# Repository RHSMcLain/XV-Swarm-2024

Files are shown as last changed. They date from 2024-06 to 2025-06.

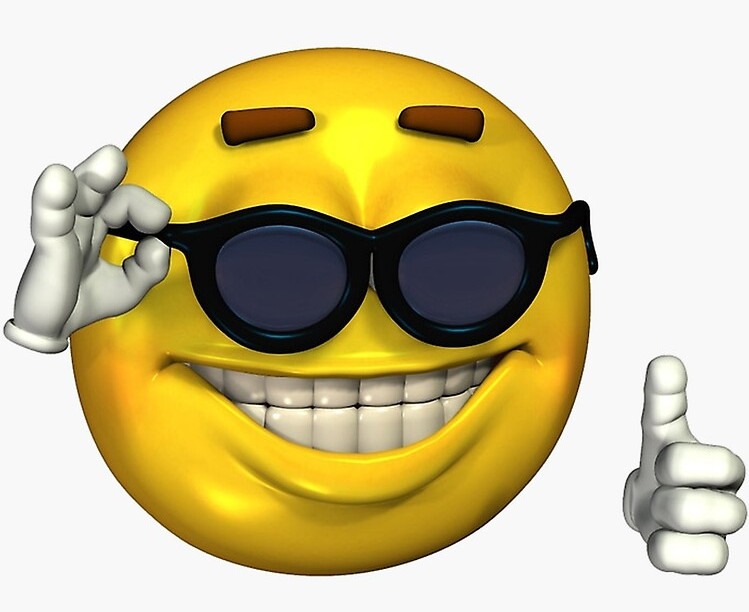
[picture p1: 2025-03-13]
Python/Resources/connecteddrone.jpg

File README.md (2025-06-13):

header
<!Happy now Bob?>
##
<details>  
    <summary>
        <b>Description of XV: Swarm</b>
    </summary>
    <p>&nbsp;&nbsp;&nbsp;&nbsp;&nbsp; The objective of this class was to create and program swarm drones ourselves. For the first few weeks of class, we worked on building &nbsp;&nbsp;&nbsp;&nbsp;&nbsp;the drones using a parts kit put together through research. To legally fly the drone, we needed approval for multiple FAA and school &nbsp;&nbsp;&nbsp;&nbsp;&nbsp;district waivers, some of which had to be revised. We also created the code from scratch, including the keyboard and flight stick &nbsp;&nbsp;&nbsp;&nbsp;&nbsp;controls, the communications from the Arduino to the flight controller, the access point, and the base station.</p>
</details>

<details>
    <summary> <b>Setup for programming<br></b> </summary>
        <setup>
            &nbsp;&nbsp;&nbsp;&nbsp;&nbsp;What you need to install:
        <details>
                <summary>Python Libraries</summary>
                <p>
                            pip3 install "requests>=2.*" <br>
                            pip3 install netifaces <i>(make sure you have C++ build tools and the SDK for your version if you are on windows)</i> <br>
                            python3 -m pip install customtkinter <br>
                            python3 -m pip install --upgrade Pillow <br>
                            pip3 install pynput <br>
                </p>
            </details>
        </setup>
</details>

<details> 
    <summary>
        <b>Regulatory Compliance</b>
    </summary>
      &nbsp;&nbsp;&nbsp;&nbsp;&nbsp;What we have applied for and received:<br>
    &nbsp;&nbsp;&nbsp;&nbsp;&nbsp;- FAA Multi-Use Waiver<br>
    &nbsp;&nbsp;&nbsp;&nbsp;&nbsp;- RSD Multi-Use Waiver<br>
    &nbsp;&nbsp;&nbsp;&nbsp;&nbsp;- § 107.35 – Operation of Multiple Small UAS<br>
    &nbsp;&nbsp;&nbsp;&nbsp;&nbsp;- Registered each drone With FAA<br>
    &nbsp;&nbsp;&nbsp;&nbsp;&nbsp;- Registered RSD with ODA<br>
    &nbsp;&nbsp;&nbsp;&nbsp;&nbsp;- FRIA zone <br>

</details>

<details> 
    <summary>
        <b>Summary of Flightstick Code</b>
    </summary>
    <p>&nbsp;&nbsp;&nbsp;&nbsp;&nbsp; Code for flight stick that outputs value for  pitch, roll, yaw, and throttle for the drone. </p>

</details>

<details> 
    <summary>
        <b>Summary of Base Station Code</b>
    </summary>
    <p><span style=width: 40px; display: inline-block;></span><span>Code for the base station and keyboard controls for pitch, roll, yaw, and throttle. The base station is responsible for transmitting and receiving signals to and from the drone's coverage area.</span></p>

</details>

<details> 
    <summary>
        <b>Summary of Access Point Code</b>
    </summary>
    <p>&nbsp;&nbsp;&nbsp;&nbsp;&nbsp; The access point provides WIFI, collects based station IP, and shares the base station IP with the drone. This code makes all of these possible. </p>

</details>

<details>
    <summary>
        <h3>Drone Building Instructions and Parts List</h3>
    </summary>
    <details>
        <summary>
            <b>Frame Construction</b>
        </summary>
        &nbsp;&nbsp;&nbsp;&nbsp;&nbsp;<a href="https://github.com/RHSMcLain/XV-Swarm-2024/blob/main/Instructions/FrameConstruction.md">Frame Instructions</a>
    </details>
    <details>
        <summary>
            <b>Wiring!</b>
        </summary>
        &nbsp;&nbsp;&nbsp;&nbsp;&nbsp;<a href="https://github.com/RHSMcLain/XV-Swarm-2024/blob/main/Instructions/Wiring.md">Wiring Instructions</a>
    </details>
    <details>
        <summary>
            <b>Code installation and Configuration</b>
        </summary>
            <details>
                <summary>
                       Code
                </summary>
             &nbsp;&nbsp;&nbsp;&nbsp;&nbsp;<a href="https://github.com/RHSMcLain/XV-Swarm-2024/blob/main/Instructions/CodeInstall.md">Code Installation Instructions</a>
            </details>
            <details>
                <summary>
                    Configuration
                </summary>
                &nbsp;&nbsp;&nbsp;&nbsp;&nbsp;<a href="https://github.com/RHSMcLain/XV-Swarm-2024/blob/main/Instructions/Configuration.md">Configuration Instructions</a>
            </details>
    </details>
    <details>
        <summary>
            <b>Parts Needed:</b>
        </summary>
        &nbsp;&nbsp;&nbsp;&nbsp;&nbsp;-<a href="https://www.digikey.com/en/products/detail/jst-sales-america-inc/A08SR08SR30K203A/9922207">8-Pin JST Cable </a> <br>
        &nbsp;&nbsp;&nbsp;&nbsp;&nbsp;-<a href="https://holybro.com/collections/autopilot-flight-controllers/products/kakute-f4-v2-4">Kakute F4 v2.4 Flight Controller</a> <br>
        &nbsp;&nbsp;&nbsp;&nbsp;&nbsp;-<a href="https://holybro.com/collections/motors/products/ripper-1404-3800kv-ultralight-brushless-motor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">Ripper Motor Four-pack</a> <br>
        &nbsp;&nbsp;&nbsp;&nbsp;&nbsp;-<a href="https://www.amazon.com/1500mAh-Graphene-Quadcopter-Helicopter-Airplane/dp/B09CTS2KY6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">Ovonic Lipo Battery</a> <br>
        &nbsp;&nbsp;&nbsp;&nbsp;&nbsp;-<a href="https://holybro.com/collections/autopilot-peripherals/products/tekko32-f4-4in1-mini-50a-esc">Tekko-32 Motor Controller</a> <br>
        &nbsp;&nbsp;&nbsp;&nbsp;&nbsp;-<a href="https://holybro.com/collections/power-modules-pdbs/products/pm02-v3-12s-power-module">Battery Cable Adapter</a> <br>
        &nbsp;&nbsp;&nbsp;&nbsp;&nbsp;-<a href="https://holybro.com/collections/standard-gps-module/products/micro-m10-m9n-gps">Micro M10 GPS</a> <br>
        &nbsp;&nbsp;&nbsp;&nbsp;&nbsp;-<a href="https://betafpv.com/products/hq-3030-2-blade-propellers-1-5-shaft-16-pcs?variant=29700573528108">16x 3-Blade Propellers</a> <br>
        &nbsp;&nbsp;&nbsp;&nbsp;&nbsp;-<a href="https://store-usa.arduino.cc/products/arduino-nano-33-iot">Arduino Nano 33 IOT</a> <br>
       &nbsp;&nbsp;&nbsp;&nbsp;&nbsp; -<a href="https://store.arduino.cc/products/nodemcu-esp8266">NodeMCU ESP8266</a> <br>
        <br><p>&nbsp;&nbsp;&nbsp;&nbsp;&nbsp; Screw and insert types below, feel free to use different than the link provides</p>
        &nbsp;&nbsp;&nbsp;&nbsp;&nbsp;-<a href="https://www.amazon.com/gp/product/B07TTQXVQH/ref=ox_sc_act_title_1?smid=A19TVI3M6WFVG7&th=1">M1.6 Brass Screw Insert</a> <br>
        &nbsp;&nbsp;&nbsp;&nbsp;&nbsp;-<a href="https://www.amazon.com/M1-6x4mm-0-35mm-Pitch-Socket-100pcs/dp/B00XP4ZWY2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">M1.6 .35mm Screw</a> <br>
        &nbsp;&nbsp;&nbsp;&nbsp;&nbsp;-<a href="https://www.amazon.com/initeq-M3-0-5-Threaded-Inserts-Printing/dp/B077CJV3Z9?th=1">M3 Brass Screw Insert</a> <br>
        &nbsp;&nbsp;&nbsp;&nbsp;&nbsp;-<a href="https://www.amazon.com/Socket-Screws-Bolts-Thread-100pcs/dp/B07CNFTK99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">M3 12mm Screw</a> <br>
        <br><p>&nbsp;&nbsp;&nbsp;&nbsp;&nbsp;Needed: 8pcs M3 x 12mm 0.5mm Pitch & 4pcs M1.6 x 4mm 0.35mm Pitch</p>
    </details>
</details>

## Contributors: 
Adam McLain,
Willem Abbassi, 
<a href="https://github.com/Kbratland" 
style="text-decoration: none">Konner Bratland</a>, 
Dylan Bratt, Nadir Chaer, Sylas Christopher, Thomas Fredricks, Lane Gilliam, Ethan Green, Xilena Hardy, Christian Hanson, <a href="https://github.com/Agupag" 
style="text-decoration: none">Connor Madriago</a>,<a href="https://github.com/assafnachum" 
style="text-decoration: none">Assaf Nachum</a>, Leo Novack, Spencer Parsons, <a href="https://github.com/drobinson-2915" 
style="text-decoration: none">David Robinson</a>,
<a href="https://github.com/bjornwroberts" 
style="text-decoration: none">Bjorn Roberts</a>, 
Max Symmes, Brendan Vasanth, <a href="https://github.com/KoderMx1" 
style="text-decoration: none">Cody Webb</a>, and Cyrus Weeden
##
<p align="center">
  animated
</p>

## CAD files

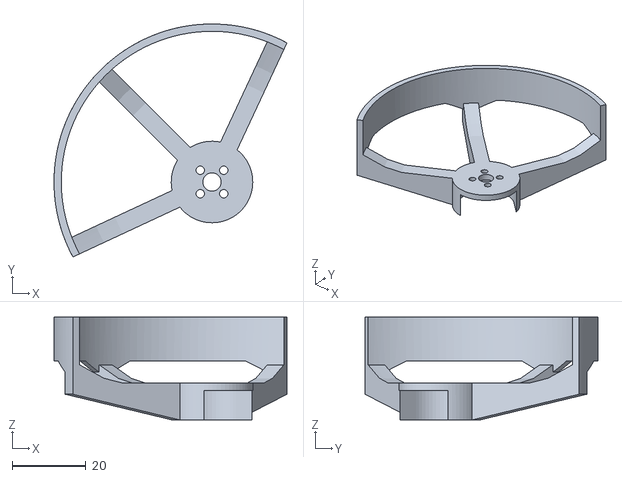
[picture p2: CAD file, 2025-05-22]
CadFIles/Prop Protector V2.stl
63.4 x 63.4 x 28.0

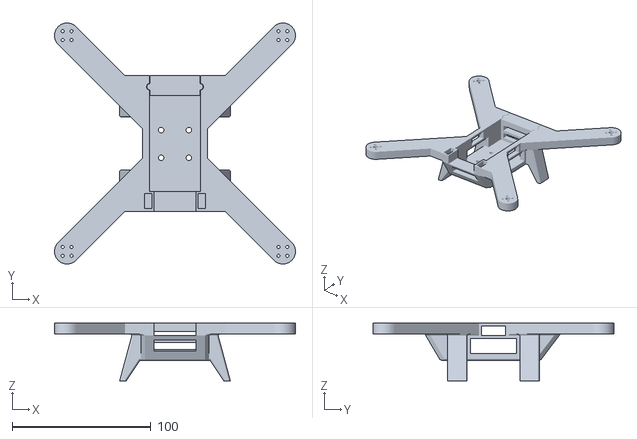
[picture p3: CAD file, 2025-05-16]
CadFIles/New Drone Body.stl
173.7 x 173.7 x 41.7

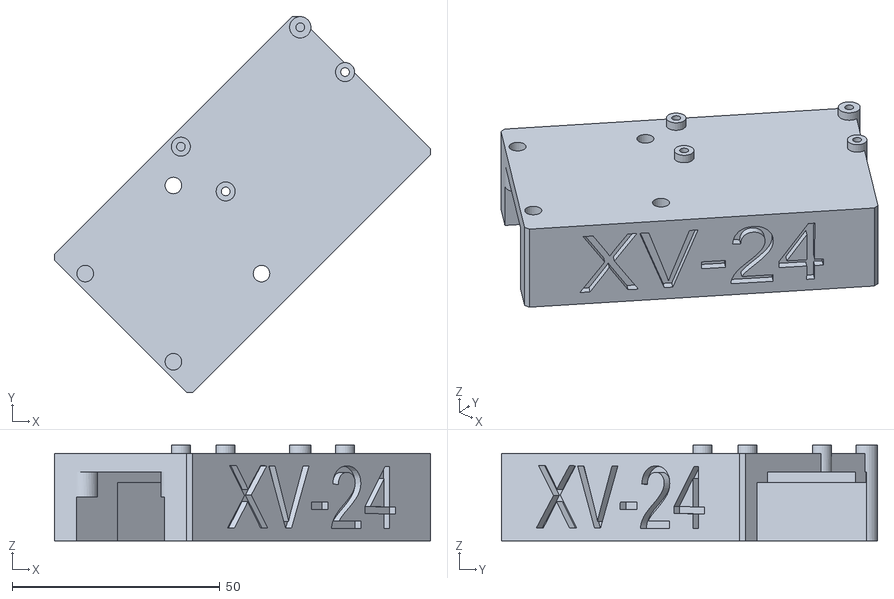
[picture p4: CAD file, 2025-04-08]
CadFIles/Harness.stl
90.5 x 90.5 x 23.0

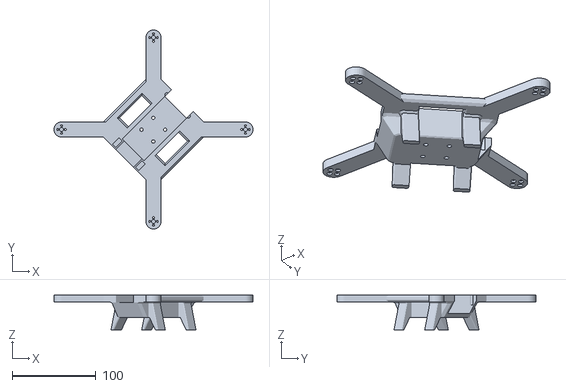
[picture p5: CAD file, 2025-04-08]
CadFIles/Drone Frame.stl
238.1 x 238.1 x 41.7

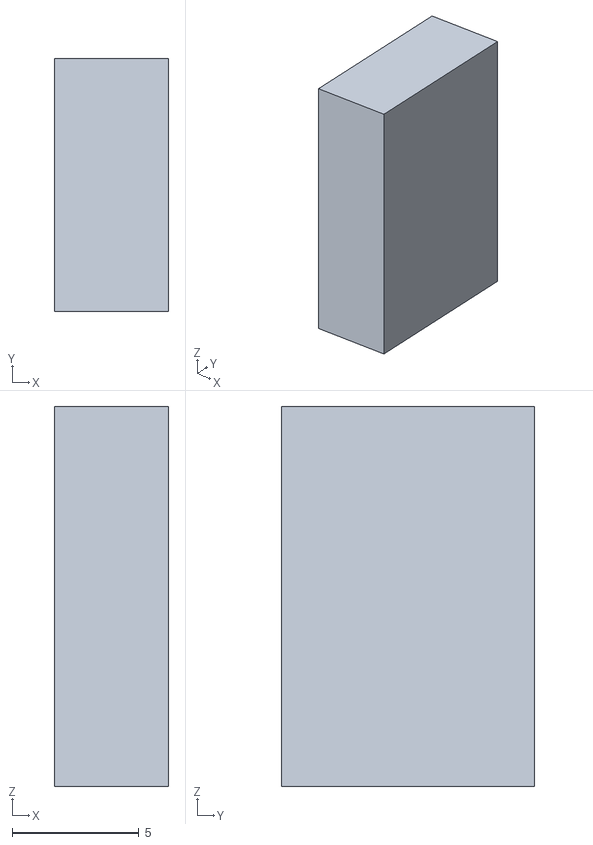
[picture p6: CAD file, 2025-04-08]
CadFIles/Key x2.stl
4.50 x 10.0 x 15.0

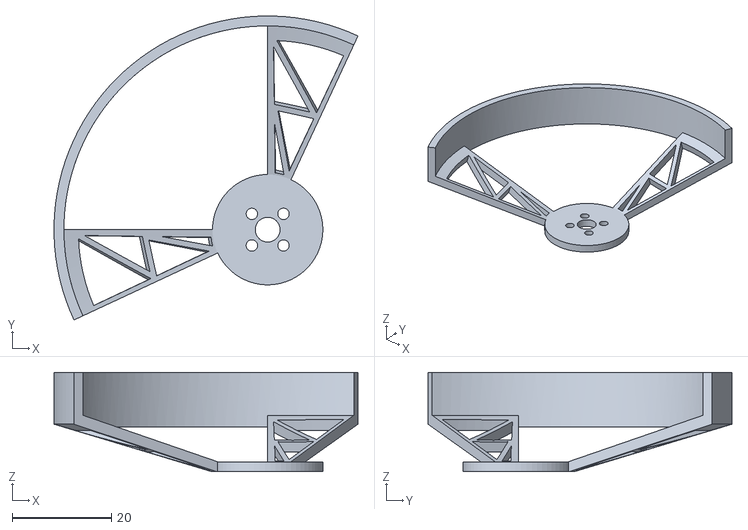
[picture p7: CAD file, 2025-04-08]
CadFIles/Prop Protector x4.stl
61.2 x 61.2 x 20.0

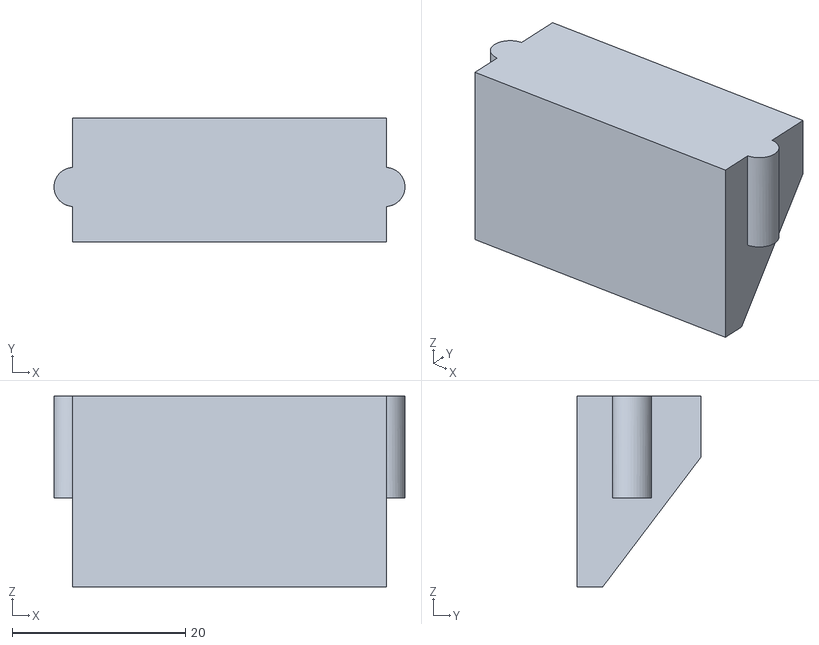
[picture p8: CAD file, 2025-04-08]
CadFIles/Holder.stl
40.5 x 14.4 x 22.0

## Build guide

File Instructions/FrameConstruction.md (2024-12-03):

header

https://github.com/user-attachments/assets/5fdc28cc-e4c6-4927-8b7a-d4b1867e7872

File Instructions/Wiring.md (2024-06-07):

header

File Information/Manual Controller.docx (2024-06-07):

1. Gather Components:

- Arduino board (e.g., Arduino Uno, Arduino Nano)

- USB keyboard

- Jumper wires

- Breadboard (optional, for easy connections)

2. Understanding USB Communication:

- USB keyboards communicate using the USB Human Interface Device (HID) protocol.

- Arduino boards don't have native USB HID support, so you'll need to use a library to interpret USB HID data.

3. Install Necessary Libraries:

- Install the "HID-Project" library in the Arduino IDE. You can do this by navigating to Sketch > Include Library > Manage Libraries, then search for "HID-Project" and install it.

4. Connect the Keyboard to Arduino:

- Connect the USB keyboard to the USB port of your computer.

- Connect the Arduino board to your computer via USB.

5. Write Arduino Sketch:

- Open the Arduino IDE on your computer.

- Write a sketch that listens for keyboard inputs using the HID-Project library.

- Include the necessary headers and define variables to store keyboard input.

- Set up the Arduino to listen for keyboard inputs and print them to the Serial Monitor for testing.

6. Test Keyboard Input:

- Upload the Arduino sketch to the Arduino board.

- Open the Serial Monitor in the Arduino IDE.

- Press keys on the keyboard and verify that the Arduino receives and displays the corresponding key codes in the Serial Monitor.

7. Map Keyboard Inputs to Drone Commands:

- Once you've confirmed that the Arduino can receive keyboard inputs, map these inputs to specific drone commands.

- Define a mapping between keyboard keys and drone movements in your Arduino sketch.

- For example, assign specific keys to control forward/backward movement, left/right movement, altitude control, yaw control, etc.

8. Integrate with Drone Flight Controller:

- Determine how you'll interface the Arduino with the drone's flight controller. This could involve using PWM signals, specific communication protocols (e.g., UART), or digital/analog signals depending on the drone's hardware.

- Connect the appropriate output pins of the Arduino to the inputs on the drone's flight controller.

9. Test Drone Control:

- Power on the drone and verify that it responds correctly to keyboard commands received through the Arduino.

- Test basic maneuvers, stability, altitude control, yaw control, and emergency stop to ensure proper functionality.

Testing:

Certainly! Testing drone control involves ensuring that your Arduino-based setup effectively translates keyboard inputs into commands that the drone's flight controller understands. Here's a more detailed approach to testing drone control:

1. Basic Movement Testing:

- Begin by testing each basic movement command individually to ensure they work as expected.

- Press the designated keys for forward ('W'), backward ('S'), left ('A'), and right ('D') movements.

- Observe the drone's response to each command and verify that it moves in the corresponding direction.

- Repeat the process for other basic maneuvers such as ascending ('Q') and descending ('E').

2. Combined Movement Testing:

- Test combinations of movement commands to ensure smooth and coordinated drone control.

- For example, try pressing both forward and left keys simultaneously to make the drone move diagonally forward-left.

- Verify that the drone responds appropriately to combined commands without any unexpected behavior.

3. Stability Testing:

- Assess the drone's stability while executing different commands.

- Command the drone to hover in place (stop all movement) and observe if it maintains a stable position.

- Test stability during forward, backward, left, and right movements to ensure the drone doesn't drift unintentionally.

- Check for any oscillations or instability that may indicate issues with control or calibration.

4. Altitude Control Testing:

- Test the drone's ability to maintain altitude using keyboard commands.

- Press the designated keys for ascending ('Q') and descending ('E') movements.

- Verify that the drone ascends or descends smoothly and maintains the desired altitude without drifting.

5. Yaw Control Testing:

- Test the drone's yaw control (rotation) using keyboard inputs.

- Press the designated keys for rotating left ('Z') and right ('C').

- Observe the drone's rotation and ensure it turns smoothly without excessive wobbling or drift.

6. Emergency Stop Testing:

- Verify the effectiveness of the emergency stop command.

- Press the designated emergency stop key ('Spacebar' or any other key assigned for this function).

- Confirm that the drone immediately halts all movement and enters a safe state.

7. Flight Duration Testing:

- Conduct extended flight tests to assess the stability and reliability of the control system over time.

- Fly the drone for an extended duration, monitoring its behavior and responsiveness to keyboard commands.

- Note any issues such as signal loss, control lag, or unexpected behavior that may arise during prolonged operation.

8. Fine-Tuning and Adjustment:

- If any issues or inconsistencies are observed during testing, make necessary adjustments to the Arduino code or control settings.

- Fine-tune parameters such as control gains, sensitivity, and response curves to optimize drone performance and control.

9. Repeat Testing:

- Repeat the testing process as needed, especially after making adjustments or modifications to the control system.

- Ensure that all commands are functioning correctly and that the drone responds predictably to keyboard inputs in various flight scenarios.

By thoroughly testing drone control functionality, you can identify and address any issues or limitations in your setup, ensuring safe and reliable operation during actual flights.

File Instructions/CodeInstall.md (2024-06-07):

header

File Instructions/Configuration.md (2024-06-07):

header

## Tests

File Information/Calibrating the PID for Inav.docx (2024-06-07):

PID Tuning Conceptual Information

PID loops, or Proportional-Integral-Derivative loops, are fundamental control mechanisms used in many systems, including flight controllers like iNav. iNav is an open-source flight control software primarily used in multirotor drones and fixed-wing aircraft. PID loops in iNav are responsible for stabilizing the aircraft by adjusting control surfaces or motor speeds based on sensor feedback.

PID tuning aims to tweak the PID loop gains so that it achieves the fastest response to command changes as fast as possible without overshooting or oscillating.

The P term controls the strength of the correction that is applied to bring the craft toward the target angle or rotation rate. If the P term is too low, the craft will be difficult to control as it won't respond quickly enough to keep itself stable. If it is set too high, the craft will rapidly oscillate/shake as it continually overshoots its target.

The I term corrects small, long-term errors. If it is set too low, the craft's attitude will slowly drift. If it is set too high, the craft will oscillate (but with slower oscillations than with P being set too high).

The D term attempts to increase system stability by monitoring the rate of change in the error. If the error is rapidly converging to zero, the D term causes the strength of the correction to be backed off to avoid overshooting the target.

Tuning PID loops in iNav involves adjusting these three terms to achieve the desired balance of responsiveness, stability, and robustness to disturbances. This tuning process often involves experimentation and fine-tuning to find the optimal gains for a particular aircraft and flight conditions. Many users rely on trial and error, flight testing, and sometimes automated tuning algorithms to optimize PID parameters.

PID Tuning steps

Finding P value:

Start by setting the Integral and Derivative values to 0. Then increase the proportional value until the controller starts to become unstable and oscillate.

A controller where the oscillations become smaller is considered a “stable” controller, as eventually it will stabilize, and when the oscillations start getting larger is an ”unstable” controller.

Once the proportional value that causes the controller to oscillate is found, take this value and divide it in half. This will be the starting P value.

Finding I value:

Once the proportional value is found, we can start to tune the integral. Always start with small steps when adjusting a PID controller, and give time between each adjustment to see how the controller reacts.

Increase the integral gain in small increments, and with each adjustment, change the set point to see how the controller reacts.

The goal of tuning the integral value is to achieve an adequate controller response or reaction time (after the initial response from the proportional is set).

If the controller starts to oscillate or become unstable, adjust the I value in the opposite direction until the controller becomes stable again. Once the controller is stable, and responding desirably… congrats! you now have a working PI controller.

Finding D value:

There are many PI controllers out there, and for certain applications, this is all that is required. But if your application could benefit from the dampening effects of the derivative, you will need to find the value that works!

Now that you have a stable PI controller, start by increasing the derivative value slowly, changing the set point, and allowing time for the controller to stabilize.

The purpose of the D value is to monitor the ramp rate of the process value and prevent it from overshooting the set point.

Then, continue to change the set point and increase the derivative until the overshoot has been dampened to an acceptable level. If the controller starts to react in a negative way (unexpected changes in the output, poor control, or oscillation) lessen the D value until the controller is stable again.

Be careful when adjusting the derivative value, as a higher value is tempting – everyone wants a smooth controller don’t they? – but too high of a derivative will start to affect the output negatively and “fight” what the P and I values are trying to accomplish.

The other concern with a high D value is if there is noise or distortion of the process value feedback, the derivative may see this as a fast change in the ramp rate, and bias the output at an undesired time.

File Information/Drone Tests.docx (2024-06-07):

Flight Tests:

1. Hover test: This test assesses the drone's ability to maintain a stable hover at a fixed altitude. Pilots check for any drifting or instability while the drone is hovering in place. It ensures that the drone's altitude hold and stability control systems are functioning properly.
2. PID Test: Tune formulas for PID.
3. Control responsiveness test: Pilots assess how quickly and accurately the drone responds to commands from the remote controller. This involves testing maneuvers such as ascending, descending, turning, and changing direction to ensure precise control over the drone's movements.
4. Flight stability test: Drones are subjected to various flight conditions, including different wind speeds and directions, to evaluate their stability. Pilots observe how the drone responds to changes in wind and if it can maintain stable flight without erratic behavior or loss of control.
5. GPS functionality test: Drones equipped with GPS undergo tests to verify the accuracy and reliability of their GPS systems. Pilots check for any discrepancies between the drone's reported position and its actual location on a map, ensuring that the GPS is providing accurate navigation data.

Kill Switch Tests Using Drone:

1. Functional Test: Before takeoff, it's crucial to verify that the kill switch is easily accessible and operational. This involves physically testing the switch to ensure it can be easily triggered in case of an emergency situation.
2. Remote Activation Test: Using the remote control, initiate the kill switch to ensure its functionality. It's imperative to confirm that the drone immediately ceases all propulsion and enters a safe mode or descends gently upon activation.
3. Range Test: To ensure effectiveness from a distance, conduct a range test of the kill switch. Walk away from the drone while activating the kill switch to verify its functionality at different distances, ensuring it can be operated remotely in emergency situations.
4. Altitude Test: Test the kill switch functionality at different altitudes to ensure its reliability regardless of the drone's height. This ensures that the kill switch can be activated successfully whether the drone is flying at low altitudes or high altitudes.
5. Obstacle Detection Test: Simulate potential obstacles such as trees or buildings and activate the kill switch while the drone is moving towards them. This ensures that the drone halts immediately upon activation, preventing collisions and potential damage.
6. Emergency Landing Test: Besides stopping propulsion, the kill switch should initiate an emergency landing procedure. Conducting this test in various terrain conditions ensures that the drone can safely touch down in emergency situations, minimizing the risk of damage to property or injury to bystanders.
7. Post-Activation Check: After activating the kill switch, conduct a post-activation check to ensure no damage has occurred and that the drone is ready for subsequent flights. This step ensures that the drone remains in a flight-worthy condition after emergency procedures are initiated.

Keyboard Code Tests:

### Yaw Control (Rotation)

1. Rotate Left (Yaw Left)
  - Key: Q
  - Test: Press and hold Q to verify the drone rotates counterclockwise. Ensure the rotation is smooth and stops immediately when the key is released.
2. Rotate Right (Yaw Right)
  - Key: E
  - Test: Press and hold E to ensure the drone rotates clockwise. The rotation should be smooth and stop promptly when the key is released.

### Roll Control (Lateral Movement)

3. Roll Left
  - Key: A
  - Test: Press and hold A to verify the drone rolls to the left. Ensure it moves laterally in a controlled manner and stops rolling when the key is released.
4. Roll Right
  - Key: D
  - Test: Press and hold D to ensure the drone rolls to the right. The movement should be lateral, controlled, and cease when the key is released.

### Pitch Control (Forward and Backward Tilt)

5. Pitch Forward
  - Key: W
  - Test: Press and hold W to check that the drone tilts forward, causing forward movement. Ensure the pitch is smooth and stops when the key is released.
6. Pitch Backward
  - Key: S
  - Test: Press and hold S to ensure the drone tilts backward, resulting in backward movement. The pitch should be smooth and halt when the key is released.

Throttle Control (Altitude Control)

7. Increase Throttle (Ascend)
  - Key: Arrow Up
  - Test: Press and hold the Arrow Up key to verify the drone ascends smoothly. Ensure the altitude increases steadily and stops rising when the key is released.
8. Decrease Throttle (Descend)
  - Key: Arrow Down
  - Test: Press and hold the Arrow Down key to ensure the drone descends smoothly. The descent should be steady and cease when the key is released.

Before Flight Test:

1. Pre-flight checks: Before every flight, pilots should perform a thorough inspection of the drone. This includes checking the battery levels to ensure they are sufficient for the planned flight duration, inspecting propellers for any damage or wear, verifying that motors are functioning correctly, and ensuring that all other critical components such as the flight controller and sensors are operational.

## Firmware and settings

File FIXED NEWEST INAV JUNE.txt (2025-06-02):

diff all

# version
# INAV/KAKUTEF4V24 8.0.1 Mar 28 2025 / 09:53:19 (ae47bcba) 
# GCC-13.2.1 20231009

# start the command batch
batch start

# reset configuration to default settings
defaults noreboot

# resources

# Timer overrides

# Outputs [servo]

# safehome

# Fixed Wing Approach

# geozone

# geozone vertices

# features
feature -OSD
feature THR_VBAT_COMP
feature VBAT
feature SOFTSERIAL
feature GPS
feature CURRENT_METER
feature PWM_OUTPUT_ENABLE

# beeper

# blackbox
blackbox -NAV_ACC
blackbox NAV_POS
blackbox NAV_PID
blackbox MAG
blackbox ACC
blackbox ATTI
blackbox RC_DATA
blackbox RC_COMMAND
blackbox MOTORS
blackbox -GYRO_RAW
blackbox -PEAKS_R
blackbox -PEAKS_P
blackbox -PEAKS_Y
blackbox SERVOS

# Receiver: Channel map

# Ports
serial 0 0 115200 115200 0 115200
serial 3 2 115200 115200 0 115200
serial 5 1 9600 115200 0 115200

# LEDs

# LED color

# LED mode_color

# Modes [aux]
aux 0 0 1 1525 1700
aux 1 3 0 1525 1925
aux 2 27 3 1550 1800

# Adjustments [adjrange]

# Receiver rxrange

# temp_sensor

# Mission Control Waypoints [wp]
#wp 0 invalid

# OSD [osd_layout]

# Programming: logic

# Programming: global variables

# Programming: PID controllers

# OSD: custom elements

# master
set gyro_zero_x = -14
set gyro_zero_y = 17
set gyro_zero_z = 12
set ins_gravity_cmss =  1031.860
set acc_hardware = MPU6000
set acczero_x = 98
set acczero_y = -16
set acczero_z = -190
set accgain_x = 4091
set accgain_y = 4097
set accgain_z = 3975
set align_mag = CW270FLIP
set mag_hardware = IST8310
set maggain_x = 81
set maggain_y = 228
set maggain_z = 360
set align_mag_yaw = 1
set baro_hardware = BMP280
set receiver_type = MSP
set blackbox_rate_denom = 2
set applied_defaults = 6
set gps_sbas_mode = WAAS
set gps_ublox_use_galileo = ON
set gps_ublox_use_beidou = ON
set gps_ublox_use_glonass = ON
set fw_autotune_max_rate_deflection = 80
set inav_default_alt_sensor = BARO
set nav_mc_althold_throttle = HOVER
set nav_auto_speed = 250
set nav_max_auto_speed = 500
set nav_max_altitude = 300
set nav_rth_altitude = 400
set nav_mc_auto_climb_rate = 250
set nav_mc_manual_climb_rate = 33
set i2c_speed = 800KHZ

# control_profile
control_profile 1

set tpa_rate = 20
set tpa_breakpoint = 1200
set rc_expo = 75
set rc_yaw_expo = 75
set roll_rate = 70
set pitch_rate = 70
set yaw_rate = 60

# control_profile
control_profile 2

set rc_expo = 44
set rc_yaw_expo = 44
set roll_rate = 34
set pitch_rate = 34
set yaw_rate = 24

# control_profile
control_profile 3


# mixer_profile
mixer_profile 1

set motor_direction_inverted = ON
set model_preview_type = 3
set motorstop_on_low = OFF

# Mixer: motor mixer

mmix reset

mmix 0  1.000  1.000 -1.000 -1.000
mmix 1  1.000  1.000  1.000  1.000
mmix 2  1.000 -1.000 -1.000  1.000
mmix 3  1.000 -1.000  1.000 -1.000

# Mixer: servo mixer

# mixer_profile
mixer_profile 2

set model_preview_type = 0
set motorstop_on_low = OFF

# Mixer: motor mixer

# Mixer: servo mixer

# battery_profile
battery_profile 1

set failsafe_throttle = 1450
set nav_mc_hover_thr = 1500

# battery_profile
battery_profile 2


# battery_profile
battery_profile 3


# restore original profile selection
control_profile 1
mixer_profile 1
battery_profile 1

# save configuration
save

# 

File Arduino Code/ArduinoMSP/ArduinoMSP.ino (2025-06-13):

/*
    * This deprecated sketch is for a drone communication system using MSP protocol and WiFi.
    * It handles waypoints, telemetry, and manual control commands.
    * It includes a search area definition and manages drone states.
    * It is designed to work on an Arduino Nano 33 IoT.
    * Requires:
    *   https://github.com/arduino-libraries/WiFiNINA/tree/master
    *   Accompanying python code running on a computer to send commands
    *   An ESP8622 or similar WiFi module to function as an access point
    * Created by: Bjorn Roberts, Konner Bratland, Connor Madriago
    * Date: 6/13/25
*/

#include <WiFiNINA.h>  //https://github.com/arduino-libraries/WiFiNINA/tree/master
#include <WiFiUDP.h>

#define MSP_ATTITUDE 108
#define MSP_SET_RAW_RC 200
#define MSP_RAW_GPS 106
#define MSP_WP 118
#define MSP_SET_WP 209

char handShake[] = "HND|-1|Verne";

char ssid[] = "XV_Basestation";        //  network SSID (name)
int status = WL_IDLE_STATUS;           // the Wi-Fi radio's status
int ledState = LOW;                    //ledState used to set the LED
unsigned long previousMillisInfo = 0;  //will store last time Wi-Fi information was updated
unsigned long previousMillisLED = 0;   // will store the last time LED was updated
const int intervalInfo = 5000;         // interval at which to update the board information
char packetBuffer[256];                //buffer to hold incoming packet
WiFiUDP Udp;
unsigned int localPort = 2390;
char ReplyBuffer[] = "Drone 1";
int wifiState = 0;               //Wifi connection state
bool firstConnectFrame = false;  //First Loop while connected to wifi
IPAddress bsip;                  //holds the base station ip address

bool serialUSB = false;
double pitch;  // pitch is broken?
double roll;
double yaw;
double throttle;
double armVar;
double navHold;
int countDis = 0;
int arming = 1500;
int updateTime = 0;
int connectTime = 0;
long t = 0;
bool isArmed = false;
bool isFailsafed = false;
bool isKilled = false;
long blinkTime = 0;
int droneState = -1;
int killswitch = 1000;
int failsafe = 1000;
int LEDpin = 13;
int blinkSpeed = 10;
bool lightOn = false;
bool bootComplete = false;  //Finished Drone Booting sequence
bool enabled = false;

uint16_t rc_values[8];
long start;

struct {
  int16_t roll;   //degrees / 10
  int16_t pitch;  //degrees / 10
  int16_t yaw;    //degrees
} msp_attitude;

struct {
  uint8_t gpsFix;  //0 or 1
  uint8_t numSat;
  uint32_t lat;        //degrees / 10,000,000
  uint32_t lon;        //degrees / 10,000,000
  uint16_t gpsAlt;     //meters
  uint16_t gpsSpeed;   //cm / seconds
  uint16_t gpsCourse;  //degrees
} msp_raw_gps;



struct ManualControlMessage {
  IPAddress sourceIP;
  String cmd;
  double yaw;
  double pitch;
  double roll;
  double throttle;
  double killswitch;
  double armVar;
  double navHold;
};

struct BSIPMessage {
  String cmd;
  IPAddress BSIP;
};

void commandMSP(uint8_t cmd, uint16_t data[], uint8_t n_cbytes) {

  uint8_t checksum = 0;

  Serial1.write((byte *)"$M<", 3);
  Serial1.write(n_cbytes);
  checksum ^= (n_cbytes);

  Serial1.write(cmd);
  checksum ^= cmd;

  uint16_t cur_byte = 0;
  while (cur_byte < (n_cbytes / 2)) {
    int8_t byte1 = ((uint16_t)data[cur_byte] >> 0) & 0xFF;
    int8_t byte2 = ((uint16_t)data[cur_byte] >> 8) & 0xFF;
    Serial1.write(byte1);
    Serial1.write(byte2);
    checksum ^= byte1;
    checksum ^= byte2;
    cur_byte++;
  }
  Serial1.write(checksum);
  while (Serial1.available()) {
    Serial1.read();
  }
}

void sendMSP(uint8_t req, uint8_t *data, uint8_t n_bytes) {

  uint8_t checksum = 0;

  Serial1.write((byte *)"$M<", 3);
  Serial1.write(n_bytes);
  checksum ^= n_bytes;

  Serial1.write(req);
  checksum ^= req;

  Serial1.write(checksum);
}

void readAttitudeData() {
  delay(100);
  byte count = 0;

  int16_t rollRec;
  int16_t pitchRec;
  int16_t yawRec;

  while (Serial1.available()) {
    count += 1;
    byte first;
    byte second;
    switch (count) {
        //first five bytes are header-type informatin, so start at 6
      case 1 ... 5:
        Serial1.read();
        break;
      case 6:
        first = Serial1.read();
        second = Serial1.read();
        rollRec = second;
        rollRec <<= 8;
        rollRec += first;
        break;
      case 7:
        first = Serial1.read();
        second = Serial1.read();
        pitchRec = second;
        pitchRec <<= 8;
        pitchRec += first;
        break;
      case 8:
        first = Serial1.read();
        second = Serial1.read();
        yawRec = second;
        yawRec <<= 8;
        yawRec += first;
        break;
      case 9:
        Serial1.read();
        break;
    }
  }
  Serial.print("Roll: " + String(rollRec / 10.0));
  Serial.print(" Pitch: " + String(pitchRec / 10.0));
  Serial.println(" Yaw: " + String(yawRec));
  msp_attitude.roll = rollRec;
  msp_attitude.pitch = pitchRec;
  msp_attitude.yaw = yawRec;
}

void readGPSData() {
  delay(100);
  byte count = 0;

  uint8_t gpsFix;
  uint8_t numSat;
  uint32_t lat;
  uint32_t lon;
  uint16_t gpsAlt;
  uint16_t gpsSpeed;
  uint16_t gpsCourse;

  while (Serial1.available()) {
    count += 1;
    byte first;
    byte second;
    byte third;
    byte fourth;
    switch (count) {
        //first five bytes are header-type informatin, so start at 6
      case 1 ... 5:
        Serial1.read();
        break;
      case 6:  //Fix, 1 is yes, 0 is no
        gpsFix = Serial1.read();
        break;
      case 7:  //Number of satellites
        numSat = Serial1.read();
        break;
      case 8:  //Combine latitude bytes
        first = Serial1.read();
        second = Serial1.read();
        third = Serial1.read();
        fourth = Serial1.read();
        lat = fourth;
        lat <<= 8;
        lat += third;
        lat <<= 8;
        lat += second;
        lat <<= 8;
        lat += first;
        break;
      case 9:  //Combine longitude bytes
        first = Serial1.read();
        second = Serial1.read();
        third = Serial1.read();
        fourth = Serial1.read();
        lon = fourth;
        lon <<= 8;
        lon += third;
        lon <<= 8;
        lon += second;
        lon <<= 8;
        lon += first;
        break;
      case 10:  //Altitude in meters
        first = Serial1.read();
        second = Serial1.read();
        gpsAlt = second;
        gpsAlt <<= 8;
        gpsAlt += first;
        break;
      case 11:  //Speed in cm/s
        first = Serial1.read();
        second = Serial1.read();
        gpsSpeed = second;
        gpsSpeed <<= 8;
        gpsSpeed += first;
        break;
      case 12:  //Degrees times 10
        first = Serial1.read();
        second = Serial1.read();
        gpsCourse = second;
        gpsCourse <<= 8;
        gpsCourse += first;
        break;
      case 13:
        Serial1.read();
        break;
    }
  }
  Serial.print("Fix: " + String(gpsFix));
  Serial.print(" NumSat: " + String(numSat));
  Serial.print(" Lat: " + String(lat / 10000000.0, 5));
  Serial.print(" Lon: " + String(lon / 10000000.0, 5));
  Serial.print(" GPSALT: " + String(gpsAlt));
  Serial.print(" SOG: " + String(gpsSpeed));
  Serial.println(" GPSCourse: " + String(gpsCourse / 10.0));
  msp_raw_gps.gpsFix = gpsFix;
  msp_raw_gps.numSat = numSat;
  msp_raw_gps.lat = lat;
  msp_raw_gps.lon = lon;
  msp_raw_gps.gpsAlt = gpsAlt;
  msp_raw_gps.gpsSpeed = gpsSpeed;
  msp_raw_gps.gpsCourse = gpsCourse;
}

void MSPLoop() {
  uint8_t datad = 0;
  uint8_t *data = &datad;
  // sendMSP(MSP_RAW_GPS, 0, 0);
  // readGPSData();
  // sendMSP(MSP_ATTITUDE, data, 0);
  // readAttitudeData();
  rc_values[0] = pitch;
  rc_values[1] = roll;
  rc_values[2] = throttle;
  rc_values[3] = yaw;
  rc_values[4] = navHold;
  rc_values[5] = armVar;
  rc_values[6] = 1500;
  rc_values[7] = killswitch;
  rc_values[9] = 1600;
  commandMSP(MSP_SET_RAW_RC, rc_values, 16);
}

void setup() {
  //Initialize serial and wait for port to open:
  Serial.begin(115200);
  if (Serial) {
    serialUSB = true;
    Serial.println("Setup");
  }
  delay(200);
  //DataSetSend();
  // set the LED as output
  pinMode(LED_BUILTIN, OUTPUT);
  //sbus_tx.Begin();
  roll = 1500;
  pitch = 1500;
  yaw = 1500;
  throttle = 885;
  armVar = 1000;
  navHold = 1000;
  WifiConnection();

  start = millis();
  delay(250);
  Serial1.begin(9600);
  Serial.begin(9600);
  rc_values[0] = 1500;
  rc_values[1] = 1500;
  rc_values[2] = 885;
  rc_values[3] = 1500;
  rc_values[4] = 1500;
  rc_values[5] = 1000;
  rc_values[6] = 1500;
  rc_values[7] = 1500;
  rc_values[9] = 1600;
  commandMSP(MSP_SET_RAW_RC, rc_values, 16);
  commandMSP(MSP_SET_RAW_RC, rc_values, 16);
  commandMSP(MSP_SET_RAW_RC, rc_values, 16);
  delay(500);
  commandMSP(MSP_SET_RAW_RC, rc_values, 16);
}  //end setup

void loop() {
  status = WiFi.status();
  if (status != WL_CONNECTED) {
    blinkSpeed = 50;
    failsafe = 1600;
  } else {
    failsafe = 1000;
  }
  //MillisStuff();
  WifiConnection();  //checks the wi-fi status
  Listen();
  DroneSystems();
  MSPLoop();

  if (wifiState == 1 && droneState == 1 && status == WL_CONNECTED) {
    Serial.println("BEGINNING PACKET");
    Udp.beginPacket(Udp.remoteIP(), Udp.remotePort());
    Udp.write("State: 1 -> 2");
    Udp.endPacket();
    wifiState = 2;
  } else if (wifiState == 2) {
    Udp.beginPacket(Udp.remoteIP(), Udp.remotePort());
    Udp.write("AmDrone");
    Udp.endPacket();
    wifiState = 3;
  } else if (wifiState == 4) {
    Udp.beginPacket(bsip, 5005);
    Udp.write(handShake);
    Udp.endPacket();
    wifiState = 5;
  }
  if (millis() - updateTime > 5000 && serialUSB) {
    Serial.println("<--------------------------->\nDrone Data");
    Serial.print("Throttle: ");
    Serial.println(throttle);
    Serial.print("Pitch: ");
    Serial.println(pitch);
    Serial.print("Roll: ");
    Serial.println(roll);
    Serial.print("Yaw: ");
    Serial.println(yaw);
    Serial.print("Armed: ");
    Serial.println(isArmed);
    Serial.print("Failsafe: ");
    Serial.println(isFailsafed);
    Serial.print("Killswitch: ");
    Serial.println(isKilled);
    Serial.println("<--------------------------->");
    updateTime = millis();
  }
  // else if (state == 5) {
  //   //call parsemanualcontrolmessage and process the results
  //   //but do it in listen
  //   // Serial.println(roll);
  //   // Serial.println(yaw);
  //   // Serial.println(pitch);
  //   // Serial.println(throttle);
  // }
}  //End Loop

void DroneSystems() {
  if (droneState == -1) {  //starting up
    blinkSpeed = 1000;
    throttle = 885;
    Serial.println("Drone State -1 | Pre-State");
    Arm(false);
    if (millis() - t > 1000) {
      t = millis();
      droneState = 0;
    }
  } else if (droneState == 0) {  //arm drone
    blinkSpeed = 1000;
    //set arming signals
    Arm(true);
    if (millis() - t > 500) {
      droneState = 1;
      t = millis();
    }
  } else if (droneState == 1) {  //nothing
    //Roll Ch 0, pitch Ch 1, Yaw Ch 3, Throttle Ch 2, Arm Ch 4
  } else if (droneState == 2) {
  }
  if (status != WL_CONNECTED) {
    if (millis() - blinkTime >= blinkSpeed) {
      LightSRLatch();
      blinkTime = millis();
    }
  } else if (droneState == -1 || droneState == 0) {  //Light Blinker
    if (millis() - blinkTime >= blinkSpeed) {
      LightSRLatch();
      blinkTime = millis();
    }
  } else if (killswitch == 1700) {
    digitalWrite(LEDpin, LOW);
  } else {
    digitalWrite(LEDpin, HIGH);
  }
  CheckModeStates();
  // delay(10);
}  //End Drone Systems

void Arm(bool armed) {
  if (armed) {
    arming = 2000;
  } else if (!armed) {
    arming = 1000;
  }
}

void CheckModeStates() {  //sets booleans of the modes for enabled/disabled
  if (arming > 1500) {
    isArmed = true;
  } else {
    isArmed = false;
  }
  if (failsafe > 1500) {
    isFailsafed = true;
  } else {
    isFailsafed = false;
  }
  if (killswitch > 1500) {
    isKilled = true;
  } else {
    isKilled = false;
  }
}

void LightSRLatch() {
  if (lightOn) {
    digitalWrite(LEDpin, LOW);
    lightOn = false;
  } else if (!lightOn) {
    digitalWrite(LEDpin, HIGH);
    lightOn = true;
  }
}

void WifiConnection() {
  // attempt to connect to Wi-Fi network:
  if (status != WL_CONNECTED && ((millis() - connectTime) > 500)) {
    if (serialUSB) {
      Serial.print("Attempting to connect to network: ");
    }
    Serial.println(ssid);
    // Connect to WPA/WPA2 network:
    status = WiFi.begin(ssid);
    //Retry every 5 seconds
    firstConnectFrame = true;
    connectTime = millis();
  } else if (status == WL_CONNECTED && firstConnectFrame) {
    Udp.begin(localPort);
    // Udp.beginPacket(Udp.remoteIP(), Udp.remotePort());
    Udp.beginPacket("192.168.4.22", 80);
    Udp.write("State: 0 -> 1 |Connected|");
    Udp.endPacket();
    wifiState = 1;

    Udp.beginPacket("192.168.4.22", 80);
    Udp.write(ReplyBuffer);
    Udp.endPacket();
    // you're connected now, so print out the data:
    if (serialUSB) {
      printBoardInfo();
    }
    firstConnectFrame = false;
    bootComplete = true;
  }
}

void SendMessage(char msg[]) {
  Udp.begin(localPort);
  // Udp.beginPacket(Udp.remoteIP(), Udp.remotePort());
  Udp.beginPacket("192.168.4.22", 80);
  Udp.write(msg);
  Udp.endPacket();
  Serial.println("Sent");
  Serial.println(msg);
  Serial.println("**********");
}

void printBoardInfo() {
  Serial.println("Board Information:");
  // print your board's IP address:
  IPAddress ip = WiFi.localIP();
  Serial.print("IP Address: ");
  Serial.println(ip);

  // print your network's SSID:
  Serial.println();
  Serial.println("Network Information:");
  Serial.print("SSID: ");
  Serial.println(WiFi.SSID());

  // print the received signal strength:
  long rssi = WiFi.RSSI();
  Serial.print("signal strength (RSSI):");
  Serial.println(rssi);
  Serial.println("---------------------------------------");
  Serial.println("You're connected to the network");
  Serial.println("---------------------------------------");
}

void MillisStuff() {  //specifies whatever this stuff is for use in the loop, to make the looop easier to read
  unsigned long currentMillisInfo = millis();

  // check if the time after the last update is bigger the interval
  if (currentMillisInfo - previousMillisInfo >= intervalInfo) {
    previousMillisInfo = currentMillisInfo;
  }

  unsigned long currentMillisLED = millis();

  // measure the signal strength and convert it into a time interval
  int intervalLED = WiFi.RSSI() * -10;

  // check if the time after the last blink is bigger the interval
  if (currentMillisLED - previousMillisLED >= intervalLED) {
    previousMillisLED = currentMillisLED;

    // if the LED is off turn it on and vice-versa:
    if (ledState == LOW) {
      ledState = HIGH;
    } else {
      ledState = LOW;
    }

    // set the LED with the ledState of the variable:
    digitalWrite(LED_BUILTIN, ledState);
  }
}

ManualControlMessage parseMessage(char buffer[]) {
  ManualControlMessage msg;
  char *token;
  token = strtok(buffer, "|");
  int i = 0;
  while (token != 0) {
    //Serial.println(token);
    switch (i) {
      case 0:
        msg.cmd = token;
        break;
      case 1:
        msg.sourceIP = token;
        break;
        if (msg.cmd == "MAN") {
          case 2:
            msg.yaw = atoi(token);
            break;
          case 3:
            msg.pitch = atoi(token);  //pitch
            break;
          case 4:
            msg.roll = atoi(token);
            break;
          case 5:
            msg.throttle = atoi(token);
            break;
          case 6:
            msg.killswitch = atoi(token);
            break;
          case 7:
            msg.armVar = atoi(token);
            break;
          case 8:
            msg.navHold = atoi(token);
            break;
        } else if (msg.cmd == "SWM") {
        }
    }
    roll = msg.roll;
    pitch = msg.pitch;
    throttle = msg.throttle;
    yaw = msg.yaw;
    killswitch = msg.killswitch;
    armVar = msg.armVar;
    navHold = msg.navHold;
    i++;
    token = strtok(NULL, "|");
  }
  return msg;
  //HAS REQUIRED PACKETS FROM LISTEN, CODE FOR MANUAL MODE HERE --------------
  //Currently does not include a break, repeats loop forever
}

BSIPMessage parseBSIP(char buffer[]) {
  BSIPMessage msg;
  char *token;
  token = strtok(buffer, "|");
  int i = 0;
  Serial.println("In parseBSIP");
  while (token != 0) {
    Serial.println(token);
    switch (i) {
      case 0:
        msg.cmd = token;
        break;
      case 1:
        msg.BSIP = token;
        break;
    }
    i++;
    token = strtok(NULL, "|");
  }
  return msg;
}

void Listen() {
  int packetSize = Udp.parsePacket();
  if (packetSize) {
    countDis = millis();
    //Serial.print("Received packet of size ");//Serial.println(packetSize);//Serial.print("From ");
    IPAddress remoteIp = Udp.remoteIP();
    //Serial.print(remoteIp);//Serial.print(", port ");//Serial.println(Udp.remotePort());// read the packet into packetBufffer
    int len = Udp.read(packetBuffer, 255);
    //Serial.println(packetBuffer);
    if (len > 0) {
      packetBuffer[len] = 0;
      if (wifiState == 3) {
        Serial.println("Parsing BSIP Message");
        //read BSID response from AP
        BSIPMessage msg = parseBSIP(packetBuffer);
        if (msg.cmd == "BSIP") {
          bsip = msg.BSIP;
          Serial.print("Base Station IP: ");
          Serial.println(bsip);
          wifiState = 4;
        }
      } else if (wifiState == 5) {
        ManualControlMessage msg = parseMessage(packetBuffer);
        if (serialUSB) {
          Serial.print("packet: ");
          Serial.print(msg.throttle);
          Serial.print(" recived at: ");
          Serial.print(millis());
        }
        if (msg.cmd == "MAN") {
          roll = msg.roll;
          pitch = msg.pitch;
          throttle = msg.throttle;
          yaw = msg.yaw;
        }
      }
    }
  } else if (armVar == 1575 && (millis() - countDis) > 1000) {
    Serial.print("Disconnected");
    armVar = 1000;
  }
}

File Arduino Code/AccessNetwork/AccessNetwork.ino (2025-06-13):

/*
    * This sketch is for a drone communication system using WiFi.
    * It is designed to work on an ESP8622 or similar WiFi module
    * Requires:
    *   https://github.com/arduino-libraries/WiFiNINA/tree/master
    *   https://github.com/esp8266/Arduino/tree/master
    *   Accompanying python code running on a computer to send commands
    * Created by: Connor Madriago, Max Symmes
    * Date: 6/13/25
*/

#include <ESP8266WiFi.h> //https://github.com/esp8266/Arduino/tree/master
#include <WiFiUDP.h>

IPAddress local_IP(192,168,4,22);
IPAddress gateway(192,168,4,9);
IPAddress subnet(255,255,255,0);
unsigned int localPort = 80;
int droneArray[3] = {1,7,9};


WiFiUDP Udp;
char packetBuffer[256]; //buffer to hold incoming packet
char ReplyBuffer[256] = "reply";       // a string to send back

void setup()
{
  Serial.begin(115200);
  Serial.println();

  Serial.print("Setting soft-AP configuration ... ");
  Serial.println(WiFi.softAPConfig(local_IP, gateway, subnet) ? "Ready" : "Failed!");

  Serial.print("Setting soft-AP ... ");
  Serial.println(WiFi.softAP("XV_Basestation") ? "Ready" : "Failed!");

  Serial.print("Soft-AP IP address = ");
  Serial.println(WiFi.softAPIP());
  Udp.begin(localPort);
}


  //add name of drone from handshake to array


void loop() {
  //listens for message
  int packetSize = Udp.parsePacket ();
  if (packetSize) {

    Serial.print("Received packet of size ");

    Serial.println(packetSize);

    Serial.print("From ");

    IPAddress remoteIp = Udp.remoteIP();

    Serial.print(remoteIp);

    Serial.print(", port ");

    Serial.println(Udp.remotePort());

    // read the packet into packetBufffer

    int len = Udp.read(packetBuffer, 255);

    if (len > 0) {

      packetBuffer[len] = 0;

    }

    Serial.println("Contents:");

    Serial.println(packetBuffer);

    // send a reply, to the IP address and port that sent us the packet we received
    // if (packetBuffer == 2006) {
      if (strcmp(packetBuffer, "Drone 1")){      
       Serial.println("It is Drone 1");
       Udp.beginPacket(Udp.remoteIP(), Udp.remotePort());
       Udp.write(ReplyBuffer);
      
      Udp.endPacket();
     }
     

  }
}

void printWifiStatus() {
  // print the SSID of the network you're attached to:

  Serial.print("SSID: ");

  Serial.println(WiFi.SSID());

  // print your board's IP address:

  IPAddress ip = WiFi.localIP();

  Serial.print("IP Address: ");

  Serial.println(ip);

  // print the received signal strength:

  long rssi = WiFi.RSSI();

  Serial.print("signal strength (RSSI):");

  Serial.print(rssi);

  Serial.println(" dBm");


}


//pulled out of loop. We think this is trying to connect to a separate client and is not needed. 
  // char intToPrint[5];

  // WiFiClient client;
  // const char * host = "192.168.4.1";
  // const int httpPort = 80;

  // if (!client.connect(host, httpPort)) {
  //   Serial.println("connection failed");
  //   return;
  // }
  // if (client.connect(host, httpPort)) {
  //   Serial.println("connection not failed");
  //   return;
  // }

  // String url = "/data/";
  // url += "?sensor_reading=";
  // url += intToPrint;

  // client.print(String("GET ") + url + " HTTP/1.1\r\n" +
  //              "Host: " + host + "\r\n" +
  //              "Connection: close\r\n\r\n");
  // unsigned long timeout = millis();
  // while (client.available() == 0) {
  //   if (millis() - timeout > 5000) {
  //     Serial.println(">>> Client Timeout !");
  //     client.stop();
  //     return;
  //   }
  // }

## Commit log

2025-02-20 The slider works for throttle now
2025-04-08 Add files via upload
    XV drone frame file
    [Drone Frame.stl, Harness.stl, Holder.stl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]
2025-04-08 cad update
    [Drone Frame.stl, Harness.stl, Holder.stl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]
2025-05-16 NavHold button
2025-05-22 prop pro yippee
    [Prop Protector V2.stl]
2025-06-02 throttle while not armed
2025-06-02 Fix dereferencing of token in parseMessage function to correctly assign sourceIP
    [Coms.cpp]
2025-06-04 Fix dereferencing of token in parseMessage function and adjust reqUpdate interval to improve data update frequency
    [Coms.cpp, ComsV2.ino]
